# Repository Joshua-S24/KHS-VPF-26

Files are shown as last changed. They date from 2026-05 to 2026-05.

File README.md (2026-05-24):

# Tiger Tower I

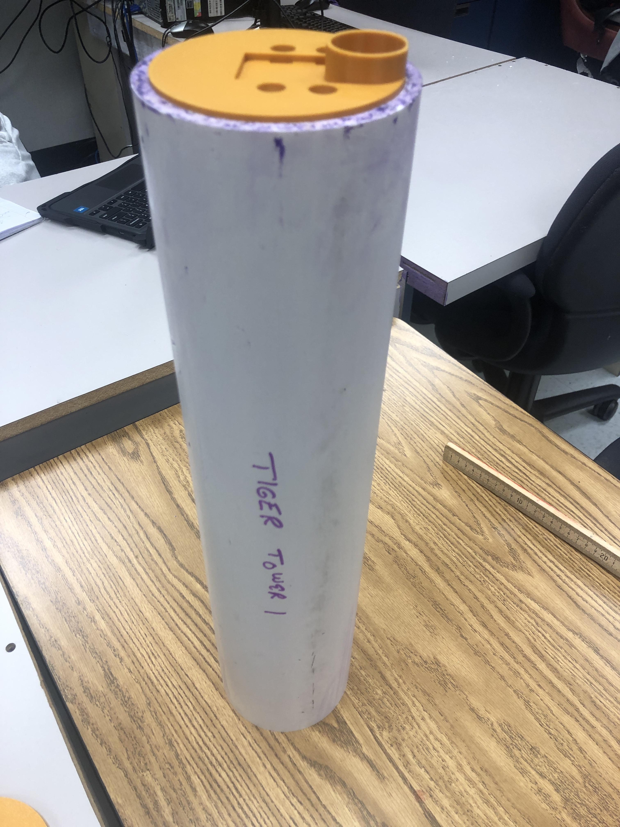
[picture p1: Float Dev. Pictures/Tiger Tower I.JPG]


This is a public repository for the Kerr Engineering Club’s vertical profiling float: Tiger Tower I. Tiger Tower I was built for the purpose of completing the 4th (ranger-class) task in the Houston Marine Advanced Technology Education (MATE) Remotely Operated Vehicle Competition.

Task Preview: https://20693798.fs1.hubspotusercontent-na1.net/hubfs/20693798/2026/2026%20MATE%20Floats%20Preview%20Mission\_RANGER\_PIONEER\_FINAL\_Updated\_10\_1.pdf

This repository is primarily meant for current members of the **Kerr Engineering Club** who are interested in the MATE ROV competition and are also interested in working on a vertical profiling float. Tiger Tower I is **incomplete** as of the 2026 competition, so this is meant to be documentation for the float to complete and improve upon it. However, non-members who are participating in the competition can feel free to use this repository as a source of information about building a vertical profiling float.

There is also a logbook that details the process of developing Tiger Tower I, which goes into further detail about the tools and decisions made during its design and construction.

Below is the documentation for the main components of the float. This was written after the competition to provide a more comprehensive and streamlined explanation of Tiger Tower I.

### Tools Used

Onshape: https://www.onshape.com/en/ (Modeling)

STLGears.com: https://www.stlgears.com (Gear Model Generation)

Gear Generator 2: https://geargenerator.com/beta/ (Gear Simulation)

## Goal

The goal was to create a vertical profiling float that can, without manual input, submerge to a given depth of a large body of water, remain stationary for 30 seconds, record the water pressure and depth between 5-second intervals, re-emerge, and wirelessly transmit data to a computer.

## The Chassis

### Body

The internals of the float are contained in a 4-inch nominal schedule 40 PVC pipe. The length of this PVC pipe was originally 56 cm before being shortened to 50 cm. (Based on measurement, the inner diameter was approximately 3.956 inches, and the outer diameter was approximately 4.504 inches.)

The reason I chose a PVC pipe was simple: it was readily available, sturdy, and buoyant. The buoyancy of a sealed PVC pipe suits our water-based buoyancy engine. The shape of the PVC pipe was cylindrical, which means that the buoyant force acting upon the float would be uniform, and not biased on one side or another. One key drawback, however, is that PVC pipes are opaque, meaning electronics inspection will require the unsealing of the float. Additionally, the 2026 competition required a safety handle that the ROV could use to retrieve it. While a design was not made in time, it was likely that a thin, 3D-printed ring with 4 support beams attached to the chassis would’ve been used to maintain the uniform shape while minimizing the additional surface area.

That particular size of the PVC pipe was chosen since it allowed for much leeway in the development of the float’s components. The long-term plan was to develop the parts, then cut the chassis down to the minimum size possible. However, the sheer size of the pipe meant that even with the largest syringes available, the float would never have been able to sink.

### Compartment Layout

The float was separated into two main compartments: the electronics and the buoyancy engine. The electronics were kept at the top. This is mainly because vertical profiling floats require radio waves to communicate wirelessly. However, the range of radio waves can be adversely affected underwater. While the float is on the surface, some amount of the bottom of the float must be submerged, meaning that the electronics should be on the top part of the float for the sake of communication. This meant that the buoyancy engine was at the bottom. Additionally, a ballast was planned to also be near the bottom of the float to provide stability.

## Buoyancy Engine

### Chosen Type of Buoyancy Engine

While a buoyancy engine was not required for the completion of this task, it was encouraged by the competition. There are two main types of buoyancy engines we could have used: an air-based buoyancy engine and a water-based buoyancy engine.

An air-based buoyancy engine would require an internal air tank, a bladder to contain the air, and a pump. The float must also experience negative buoyancy by default. The bladder must also be exposed outside the float. While the bladder is deflated, the float sinks. To go back up, air could be pumped into the bladder to give the float more volume, giving the float positive buoyancy.

A water-based buoyancy engine would require a syringe and a motor-powered linear actuator. A syringe can be used in place of a pump and bladder because it can store, intake, and expel water with the help of a linear actuator. The float would begin at positive buoyancy before the syringe draws in water, causing it to sink. Once the float needs to surface, the syringe can expel the water to bring it back to positive buoyancy. For its simplicity, we picked the water-based buoyancy engine.

### Syringe

I had the option of using a large syringe or multiple small syringes. While a large syringe could’ve easily been used, I had to consider the size of the syringe relative to both the electronics compartment and the mechanism needed to push and pull the syringe. Additionally, the more water is taken in, the more power the motor would need. Finally, the float would only need just enough water for it to sink and float. Sinking and rising slowly would’ve been beneficial in finding neutral buoyancy, which was necessary in keeping the float still. Therefore, I decided to use three 60 mL syringes, which stored a total of 180 mL. In hindsight, this was far from being enough to sink the float due to the size of the chassis.

### Linear Actuator

The linear actuator, in retrospect, easily took the most time out of this project. Despite it still being a non-functional state, I believe that it was a necessary sacrifice in the long term due to the potential for mass-producing a linear actuator. The reason why I decided to make a linear actuator instead of buying one was simple: cost. While the cost of linear actuators isn’t insurmountable, our club does not currently have the funds to casually buy an actuator. The cost of one relative to every other component of the float would mean that I would have to design the entire float around it. While that is not necessarily a downside, making adjustments to the float’s design could become restrictive by buying an actuator. Moreover, the power that a linear actuator offers is simply too much for what is required for the buoyancy engine. The lower I managed to find was able to exert a force of 40 pounds, which could actually end up compromising the float if I did not implement limit switches for whatever reason. I would need no more than 5 pounds to extract the maximum amount of water out of the largest syringe I could find. Therefore, I found it better long-term to design and 3D-print parts of a weaker linear actuator that can be mass-produced and adjusted to my liking.

The actuator itself had a 4:1 gear ratio, which was presumably sufficient for expelling and drawing in 180 mL of water. The gearbox and gears were 3D-printed with PLA, while the arm and its container were made out of PVC pipes. The PVC arm contained a cork with an indent and a hole made to fit an 1/4 in. nut and bolt. This would let the motor rotate the bolt, which would extend the arm up to a given stroke length while exerting force. Since the barrel of our syringes was 5 inches, the stroke length had to be 5 inches as well, which meant that I needed to reserve more than 10 inches (25 cm) of space for the buoyancy engine. For future attempts at making (or buying) a linear actuator, I would prioritize reserving space above all else, because my design was too long and wide.

## Electronics

### Circuitry

The electronics compartment had 2 sections. The first section, located at the top of the float, would have had the batteries, the switch, the fuse, the microcontroller, the motor controller, and the pressure sensor. The float itself was powered by 4 AA NiMH batteries, which possessed 4.8V in total. There was wiring that led to the second section, which contained the motor for the buoyancy engine and limit switches for the linear actuator.

The linear actuators required limit switches to prevent over-extension or over-retraction without tripping the fuse. This helps control the stroke range of the actuator. Most linear actuators possess power diodes so that if the arm triggers a switch, the arm cannot go past the switch and can only go in the reverse direction. However, we had no diodes that could handle more than 1 amp, meaning that I had to hook up the limit switches to the digital pins of a microcontroller. I then programmed them so that if there was a signal on the digital pin, then the function to extend in a given direction would be disabled.

At one point, there were also plans to include an SD card module. This ended up being discarded due to a lack of time and necessity, as the Pico had enough storage to store data for at least two vertical profiles.

### Microcontroller

The microcontroller I chose was the Raspberry Pi Pico W. This was because the microcontroller was compact, had innate Wi-Fi and Bluetooth capabilities, and possessed the computing power needed for the task. The Raspberry Pi Pico W also has an on-board buck boost converter, which can convert a range of voltage inputs to 5V, which can then be used to power a variety of electronics on the float.

### Data Recording and Transmission

The pressure sensor is the main way for data to be recorded. The sensor needed to be hooked up to a power source and an analog pin to return readable data. This sensor would then emit a signal between 0V and 3.3V, which would be used to determine the pressure of the water, as well as the current depth of the float, based on the density of the water. This depth could then be used in an algorithm to find neutral buoyancy, adjusting the syringe if it changed in a given time interval.

To communicate with the mission station, I wanted to use a Wi-Fi signal with a website interface. While this wasn’t ineffective, the nature of Wi-Fi’s high frequency meant that it could not penetrate through water easily. This meant that the float could only maintain a connection with the mission station while it was on the surface, and submerging to complete a vertical profile would break that connection. While workarounds were possible, an alternative could have been to use a microcontroller with a LoRa radio, like the Adafruit LoRa Radio FeatherWing. Long Range (LoRa) signals are designed to transmit small chunks of data across long distances, which would have been perfect for this scenario. Additionally, having a LoRa signal receiver on the mission station meant that we could avoid the hassle of having to connect and reconnect for every attempted profile.

## Conclusion and Future Improvements

The main obstacles in the completion of this project were time and a lack of manpower. While I had a design team for the float, due to other obligations, they were not able to assist. Taking rigorous courses like AP Calculus BC, AP Physics C: Mechanics, and AP Physics C: Electricity and Magnetism forced me to manage my time to contribute. Additionally, other team members were working on the ROV, which made up 75% of the competition. Therefore, I took it upon myself to focus on the float so that, at least, the float would be working well before the next competition.

With that being said, there are some glaring issues with this design that need to be addressed by future team members. One focal point of any vertical profiling float design is volume. Tiger Tower I was simply too big and did not respect the density of PVC, meaning that even with a large, 500 mL syringe, it would still need around 2.5 lbs of ballast to even reach neutral buoyancy. To put it succinctly, it either needs to be smaller or the chassis material needs to be replaced with something denser.

However, making the float smaller is easier said than done. While the electronics compartment won’t struggle with a decrease in size, the current linear actuator design would beg to differ. If we still wanted to commit to a custom-made linear actuator design, it would be best if, somehow, the length of the engine could decrease relative to the decrease in the chassis’ length. Additionally, the actuator’s design is too wide and should be streamlined to fit into a smaller diameter.

Finally, the Raspberry Pi Pico W can meet our requirements, but for the sake of convenience, it may be better to just buy two Adafruit LoRa Radio FeatherWings to make communication easier. This way, we can eliminate the need for an online interface and the need to re-establish a connection, only relying on choosing a certain frequency to receive.

Even though this project failed, I was able to gain a whole new insight into the process of designing a vertical profiling float and robotics in general, thanks to this competition. Our circumstances were dire, and yet our team managed to place 3rd in the Houston MATE ROV Competition, despite it being our first time competing, so I believe that our next team will have much more to offer. Additionally, doing research for this project took up a good chunk of time, and even now, many oversights could’ve been addressed sooner. I hope my findings are useful to future club members interested in building a vertical profiling float, as well as other students interested in this sort of technology.

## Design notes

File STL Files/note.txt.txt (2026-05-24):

Below are some details that may or may not have been mentioned.

The arm itself was a 1/2 in. Schedule 40 PVC Pipe. The pipe combined with the Nut Holder had a length of around 5 inches, which was the intended stroke length. I don't necessarily recommend that this particular measurement is used; rather, these were the measurements that the STL files were built around.
The nut and rod used were probably not M7. It was far more likely that both were 1/4 inches.

Gear Generator Schematic: https://geargenerator.com/beta/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
Gear STL File Source: https://www.stlgears.com/
The gearbox had a 4:1 gear ratio, and all gears had a module of 1 and a pressure angle of 25 degrees. When making your own gearbox, it is best to distance each gear based on the inner diameter (excluding teeth) to ensure proper meshing. There were three gears in total. The smallest gear had ten teeth and was placed on the motor directly. The compound gear had a 20-tooth gear on the bottom and a 12-tooth gear on the top. The compound gear was placed on a rod with a single R4AZ bearing. The final gear was a 24-tooth gear that was placed on the threaded 1/4 rod.
Additionally, most of the holes these gears had were INACCURATE, and had to be adjusted in some way after they were printed.

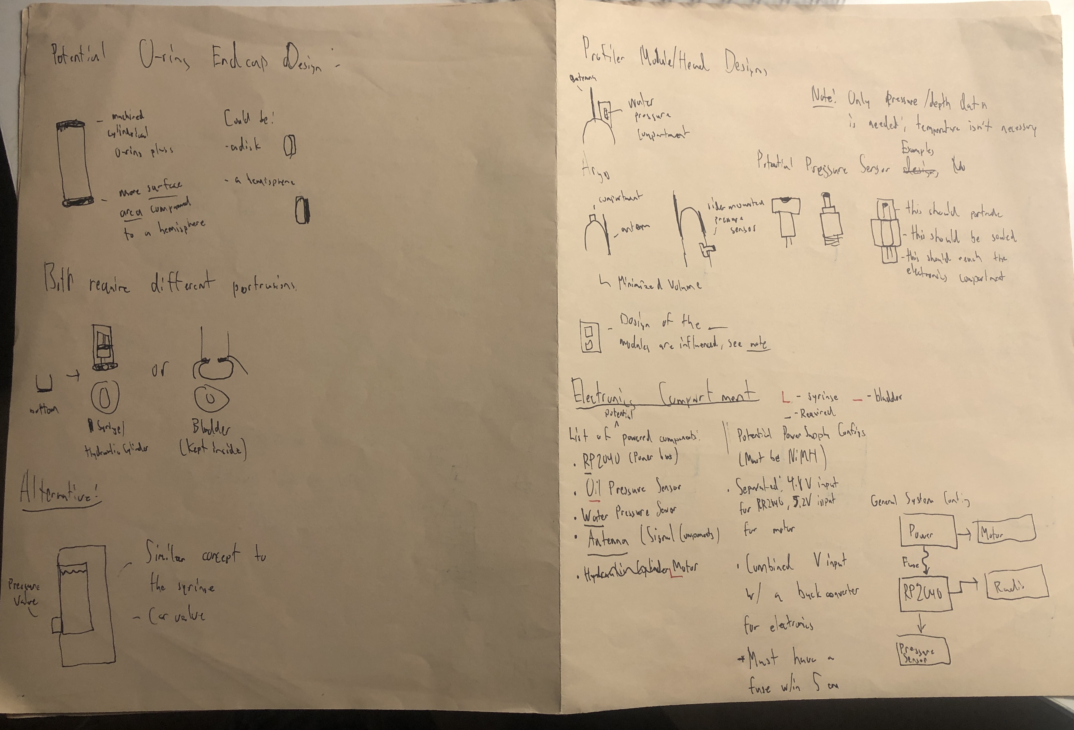
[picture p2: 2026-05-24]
Float Dev. Pictures/Rough Concept Draft Page 2.JPG

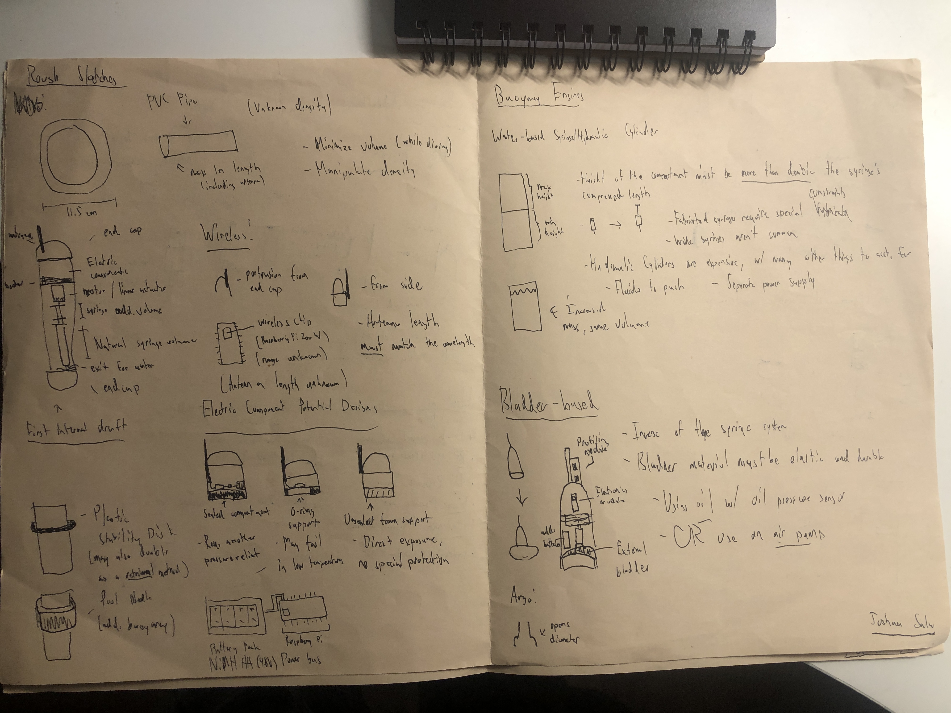
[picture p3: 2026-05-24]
Float Dev. Pictures/Rough Concept Draft Page 1.JPG

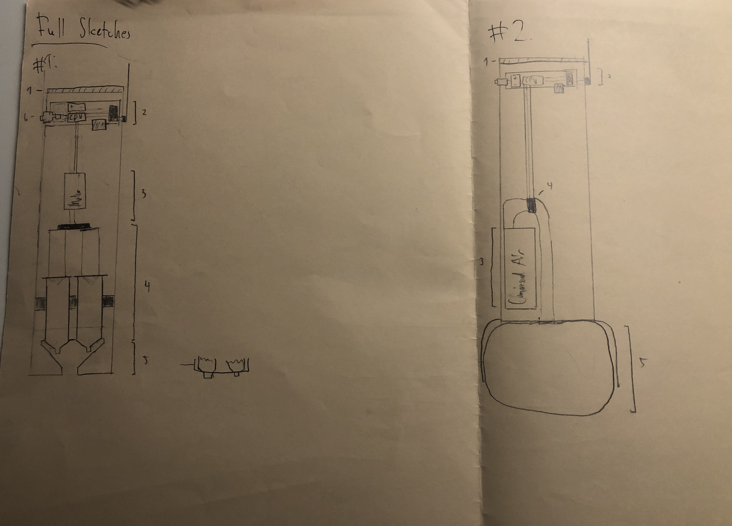
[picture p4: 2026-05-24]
Float Dev. Pictures/Buoyancy Engine Sketches.JPG

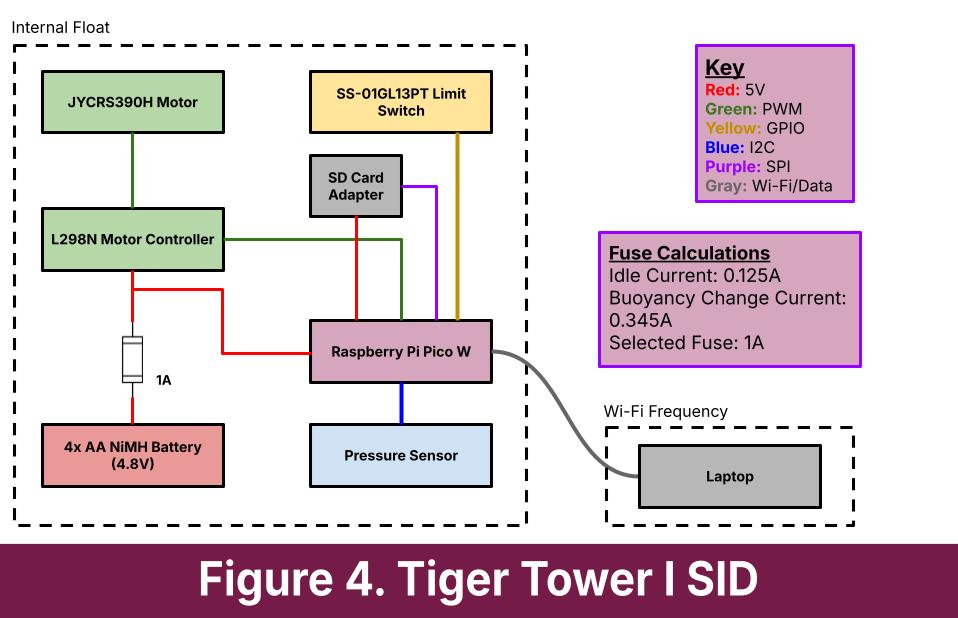
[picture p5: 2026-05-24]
Float Dev. Pictures/VPF SID Draft.jpg

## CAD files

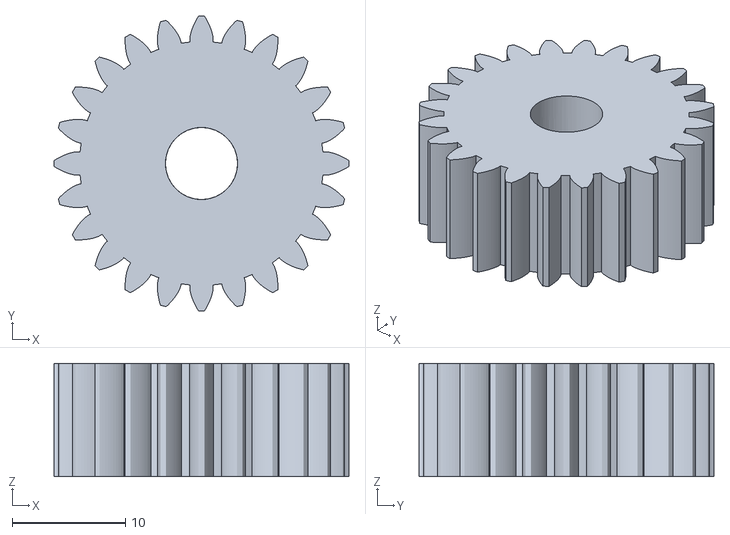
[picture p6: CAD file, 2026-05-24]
STL Files/Gears/NSpur_M1_Pa25_Z24.stl
26.0 x 26.0 x 10.0

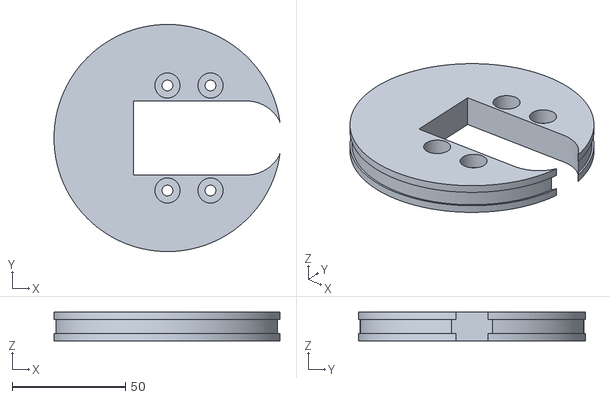
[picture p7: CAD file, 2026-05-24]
STL Files/LAGearbox/LAGearbox - HolderV2.stl
100.0 x 100.5 x 12.7

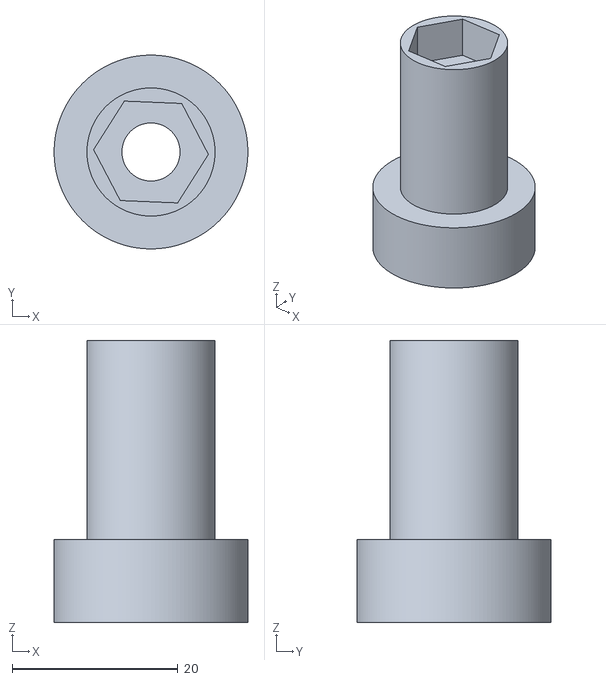
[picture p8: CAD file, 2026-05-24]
STL Files/M7NutHolder - V2.stl
23.4 x 23.4 x 34.0

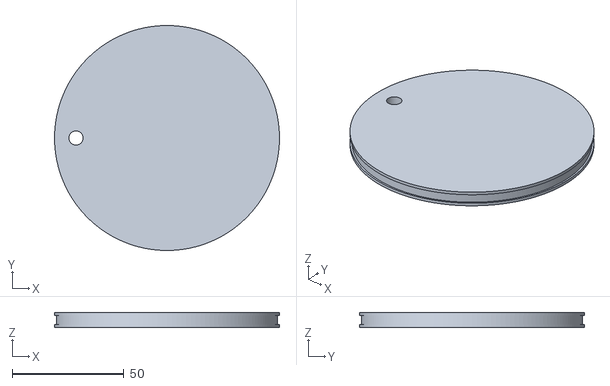
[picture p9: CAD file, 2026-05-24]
STL Files/Electronics Plate - V2.stl
100.5 x 100.5 x 6.50

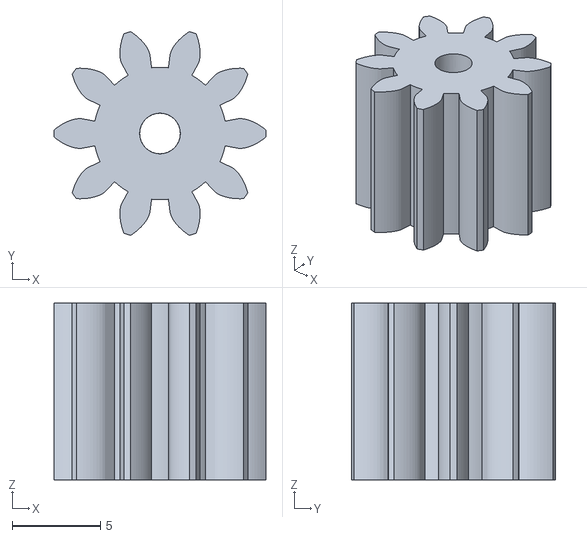
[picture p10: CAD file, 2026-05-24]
STL Files/Gears/Gear1-Spur_M1_Pa25_Z10.stl
12.0 x 11.5 x 10.0

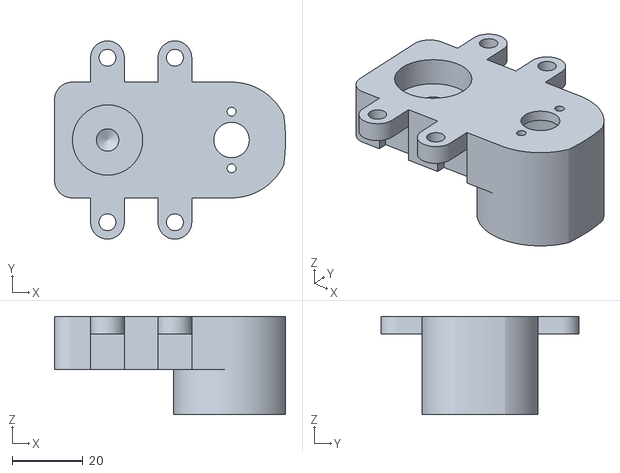
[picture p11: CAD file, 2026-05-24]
STL Files/LAGearbox/LAGearbox - Part 1.stl
65.2 x 56.0 x 27.7

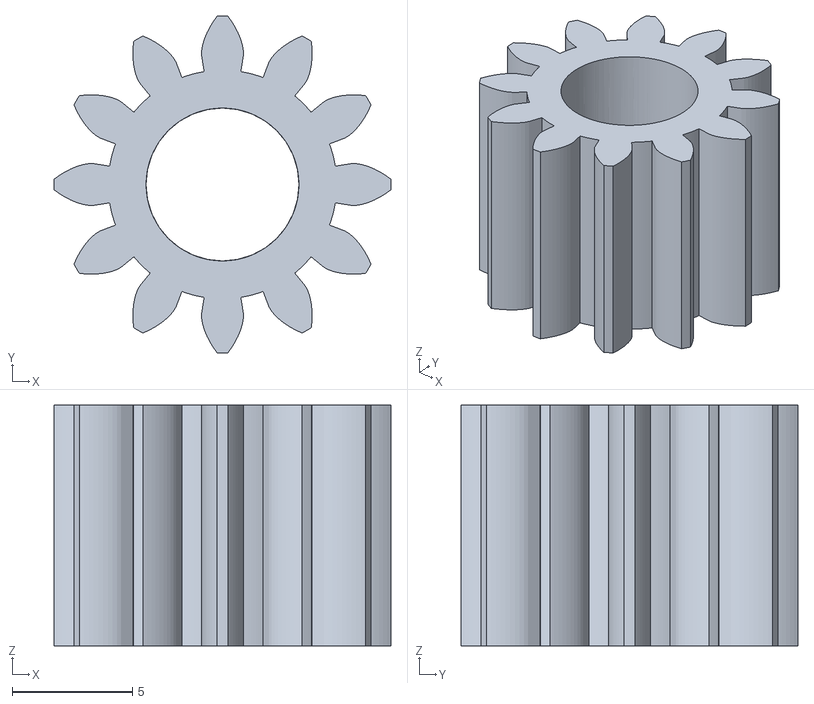
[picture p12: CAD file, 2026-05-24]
STL Files/Gears/NSpur_M1_Pa25_Z12.stl
14.0 x 14.0 x 10.0

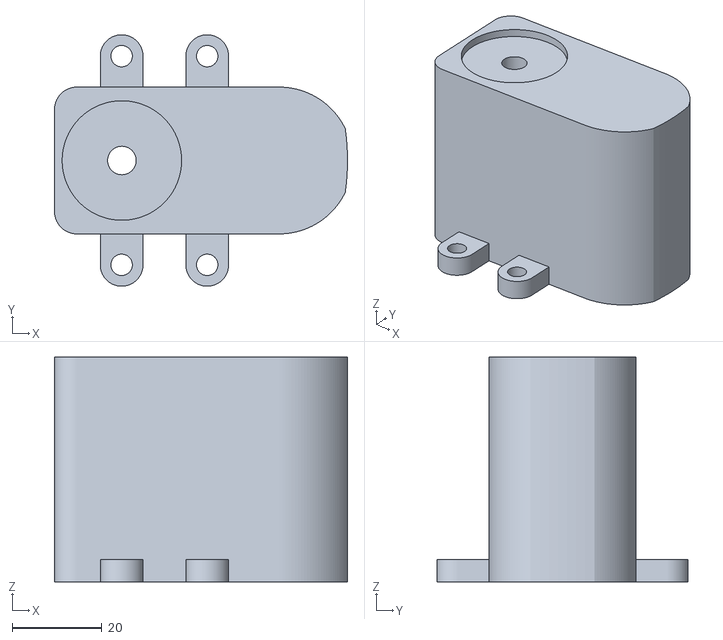
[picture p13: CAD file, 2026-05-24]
STL Files/LAGearbox/LAGearbox - Part 2.stl
65.2 x 56.0 x 50.0

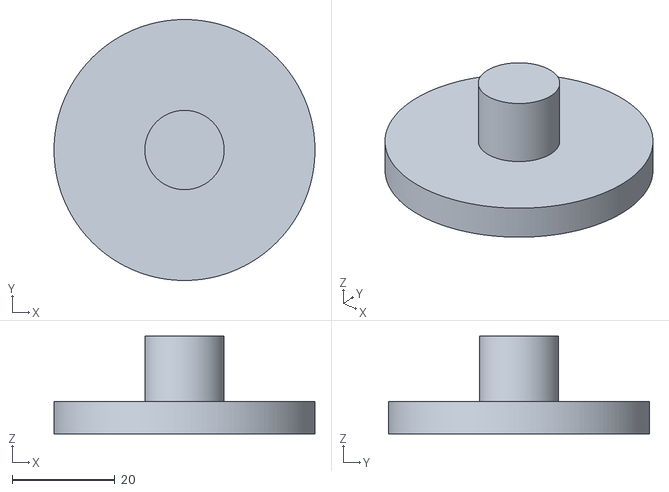
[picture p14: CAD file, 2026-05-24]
STL Files/Piston.stl
50.8 x 50.8 x 19.0

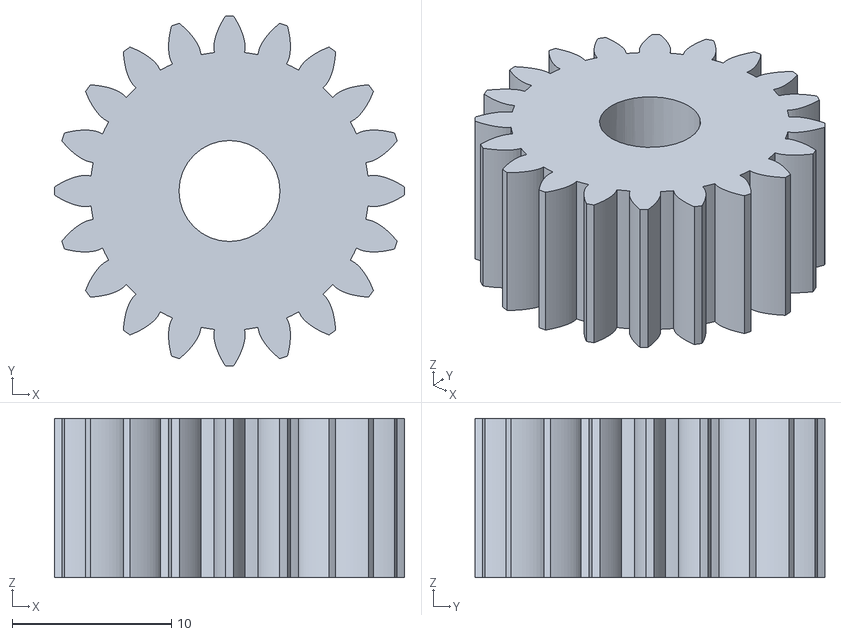
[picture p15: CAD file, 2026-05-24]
STL Files/Gears/GearboxSet2 - 20TSpurGear.stl
22.0 x 22.0 x 10.0

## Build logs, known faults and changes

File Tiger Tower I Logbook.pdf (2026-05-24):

# Tiger Tower I Logbook

## Written By Joshua Salu

## Foreword

This is a public copy of the logbook I made for the vertical profiling float that is to participate in the Houston MATE 2026 competition under the Kerr Engineering Club, also known as Kerr Robo Incorporated. This logbook will often reference links and files that may not be accessible; however, the intent of this logbook is to give insight into the construction of the float without external resources.
Additionally, while there was initially supposed to be a design team, due to student-related circumstances as well as a lack of time, all of the work related to the vertical profiling float was delegated to me, while all other team members were to work on the ROV. While I was unable to finish the float due to the urgency of the ROV, I have made this logbook public so that future members of the team can learn from my efforts.

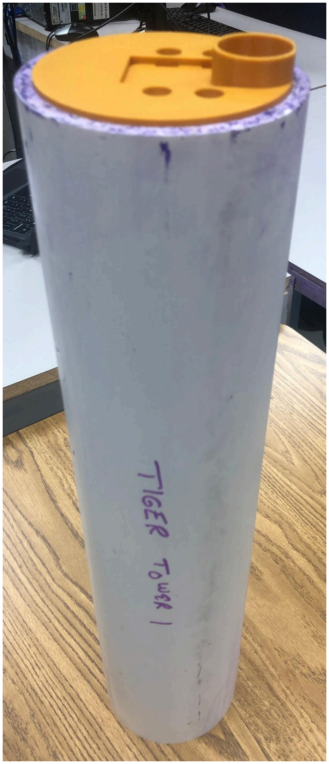
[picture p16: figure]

1/15

## Beginning Task #4

Today, the meeting was dedicated to coming up with a design for the vertical profiling float in task #4 of the MATE ROV competition.

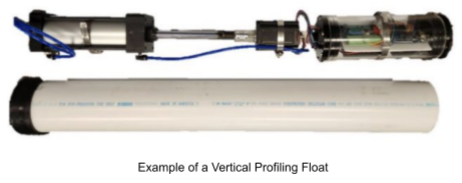
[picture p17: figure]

Task #4 involves constructing a vertical profiling float separate from the ROV to submerge in water and complete vertical profiles autonomously. The reason why I decided to prioritize this first is that this component is separate from all other tasks. To elaborate, tasks 1-3 are only possible with the ROV. Additionally, the ROV itself is being developed by Abdul right now, meaning very few tasks can be progressed. Therefore, it would be best to develop the float simultaneously.

One of the first things decided was that I would use a PVC pipe as the chassis. PVC is sturdy, reliable, cheap, and readily available. There are multiple ways to accomplish the construction of a vertical profiling float, and one of the key decisions in this process is the choice of our buoyancy engine. However, this choice, and the rest of this process, is complex and will require additional research to make some drafts.

2/10

After conducting extensive research, I have split up the vertical profiling float into 3 parts: the chassis, the electronics compartment, and the buoyancy engine.

## Chassis

The chassis is mostly simple in concept: it protects all internal components of the float. However, where it gets complex is the required holes, sealing, and pressure relief.

The chassis requires at least one hole for the pressure sensor, which will be required to record data during each vertical profile. An additional hole will also need to be made for a switch, so that it can be deployed by hand. The diameter and location of this hole are currently unknown, although it will likely be within the electronics compartment. The exact means of sealing the chassis is currently unknown. Any necessary holes will be sealed with silicon or epoxy. However, the float itself requires some form of pressure relief. There are two ways to accomplish this: corks or o-rings. Corks (or rubber stoppers) can be friction-fit into a hole to prevent fluids from coming in while allowing for pressure relief. O-rings are rubber gaskets that fulfill a similar function, but only when fit to the material. (In other words, the o-ring must be wrapped around something so it can seal the compartment.) Corks are easier to remove and modify, but take up additional space. O-rings take up less space but cannot have their circumference manipulated by any means. As of now, the current diameter of the chassis is 10 cm, and its height is around 56 cm.

## Electronics Compartment

The electronics compartment is meant to power the float so that it can record vertical profiles automatically. The key components of this compartment are the power source, the fuse, the motor, the pressure sensor, the breadboard, and the microcontroller. Currently, I am planning to use 4 AA NiMH batteries to power the float. This will provide us with a voltage of around 4.8V. NiMH (Nickel Metal Hydride) batteries are one of two allowed types of batteries for providing power. NiMH batteries can also be recharged. As per MATE’s safety regulations (ELEC-NRD-003), I must use a 2 amp fuse (if I am using NiMH batteries), and it must be within 5 cm of the power source. These batteries will also power a 5V-12V motor, but the details of the motor itself are currently unknown. The pressure sensor will also require power of its own, and its details are also unknown. The breadboard itself will likely be a typical half-size perma-proto breadboard. The microcontroller itself will be a Raspberry Pi Pico W. This microcontroller was chosen due to its compact size, low price, and innate wireless capabilities. Should the wireless capabilities be insufficient, a radio module can be connected.

## Buoyancy Engine

The buoyancy engine is the most important part of the float, as it decides the design of the majority of the float, as well as how it will manipulate the float to conduct vertical profiles. For context, all objects on Earth are subject to gravity, which is mass times the acceleration from gravity (9.81 m/s^2). All objects submerged in water experience a force of buoyancy opposite to gravity, which is the product of fluid density, gravity, and the volume of the object. For an object to float, the buoyant force must exceed the gravitational force. The opposite is true for an object to sink. An object will remain in equilibrium if the gravitational force and buoyancy are the same. In other words, if those conditions are met, the object will neither sink nor float and remain still, which is vital to taking vertical profiles at any given depth.
There are two main types of buoyancy engines: water-based engines and air-based engines. Both manipulate the force of buoyancy within water to float, sink, or remain neutral. Water-based engines use either a large syringe or a hydraulic cylinder to intake water, increasing the mass of the float to strengthen the force of gravity. Air-based engines use a bladder and an air tank (or some other fluid) to expand the bladder, increasing the volume of the float to strengthen the force of buoyancy. It should also be noted that water is many times denser than air. To be specific, water has a density of 1,000 kg/m³, while air has a density of about 1.225 kg/m³ at sea level. (Density can vary based on conditions, like temperature). Given our limitations, it is likely best to design a water-based buoyancy engine using syringes.

2/13

We have made the decision to use a water-based buoyancy engine for the vertical profiling float. Because I am using syringes, it is guaranteed that I will use a motor to construct a mechanism that converts rotational motion into translational motion. To elaborate: as the motor revolves, an object connected to that actuator will move forward and backward.

## Syringe Choices

There are two potential designs to consider: one using smaller syringes and one using a custom, larger syringe.

The former involves using readily available syringes to intake water. They will take up less space and require less force to push down. In exchange, the syringes cannot intake as much volume of water, which could be insufficient for functionality in the worst-case scenario. In the average case scenario, this could lead to a slow descent, which is not inherently negative but should be accounted for.

Currently, a syringe holder has been designed to fit 3 60 mL syringes, while also functioning as a cork to do away with the need for adhesives. (This could change in the future.)

A larger custom syringe will be harder to implement, as it will require a friction-fit disk, as well as more power from the motor that could exceed our given limit. It will also be larger, requiring more space in the chassis. In exchange, a larger syringe can ensure that the float can sink or float, though finding neutral buoyancy may be harder as a result. Currently, I will go with the first design unless it is found that the changes in mass provided by the smaller syringes are insufficient.

## Linear Motion Mechanisms

The mechanism itself can also have two (or more) designs. One option is to use a linear actuator using a screw mechanism. However, the implementation of this design is complex and must be researched. Additionally, a linear actuator must be designed rather than bought. A bought linear actuator will increase the cost by a great amount, while also potentially being unfit for our float. Creating a linear actuator will give us more agency in the design while also keeping costs low.

Therefore, it may be simpler to go with a slider-crank linkage (or other similar mechanisms like the sun-planet gear or scotch yoke). All three mechanisms use an apparatus with a motor attached to the center and a rod being held to prevent vertical movement, resulting in the rod oscillating horizontally. (Implementation of the linear actuator is not limited to these options; these are merely suggestions at the time of writing. All given flaws of these mechanisms are not fully realized as of yet.)
In both cases, the linear actuator will be attached to a piston that will connect to the syringe(s).
2/18

For now, I’ve shifted my focus to the construction of the electronics compartment. As mentioned earlier, the key components of this compartment are the power source, fuse, motor, pressure sensor, breadboard, and microcontroller. The switch will also be considered a component of the electronics compartment. This switch can be implemented in two ways.

## Switch Designs

Lever Switch w/ Cap

Pros | Cons
- PVC structures already exist that can make implementation easy ● Easy to tell if the float is on or off | ● Cannot be toggled at a moment’s notice ● Is not sealed at all points in time; improper sealing can cause extreme damage w/o safeguards ● Would likely require a protrusion; depressing the material could worsen the previous con

Push-Button Switch w/ Membrane

Pros | Cons
- Faster toggling ● Always sealed | ● Harder implementation time; the design would have to consider many factors on the outside, compared to a lever switch ● May require a visual indicator to tell if the float is powered or not

For now, I will go with the lever switch. Ideally, the lever will be small, such that it can be toggled with one finger. This way, I could end up using a membrane instead of a cap (if possible).

To allocate space for this compartment, the breadboard and microcontroller will be given a container (dubbed the electronics hub) so that all wiring is connected and made easily accessible. Additionally, the power source will be kept separate from this hub to accommodate the removal of batteries. The fuse, consequently, will also have to be kept outside of the hub to comply with regulations. To elaborate, the fuse must be within 5 cm of the power source. This also means that the switch will need to be kept in close proximity to the power source. The motor and pressure sensor will also be kept separate from the hub, but their wiring will connect to the hub to be controlled by the microcontroller. Finally, it was found that powering the motor and pressure sensor using the 3.3V out pin of the Raspberry Pi Pico W is inadvisable. Therefore, I will supply power to these devices separately, which means that I will be using 9-12V instead of the planned 4.8V. This may also involve the use of a step-down transformer within the circuit. With this in mind, I have begun to design potential designs and prototypes for the electronics hub.

2/23

Custom designs for the electronics hub have been drafted. The hub itself can be made of currently existing objects, like jars or PVC pipes. They are easy to seal and drill holes in, but their size and design cannot be customized easily. While this option isn’t ruled out (by virtue of convenience), I decided to create designs on a platform called Onshape. Onshape is a free CAD system that uses cloud architecture. We’ve decided to use this program because it can be accessed on any computer, and members can collaborate on the same design.
To make a competent design, I would decide on using 3D printed prototypes for precise measurements and features. Additionally, 3D prints are not perfect, and may have defects that may or may not be able to be fixed. Any imperfections or oddities may also affect how I approach the remaining tasks. Finally, these designs will also help us evaluate the use of PLA and other 3D printing filaments to make the shell, as well as other
components. Therefore, I have come up with designs to observe and test various characteristics that can be utilized in the final design. Using Onshape, we’ve been able to fully design 2 prototypes for the hub.

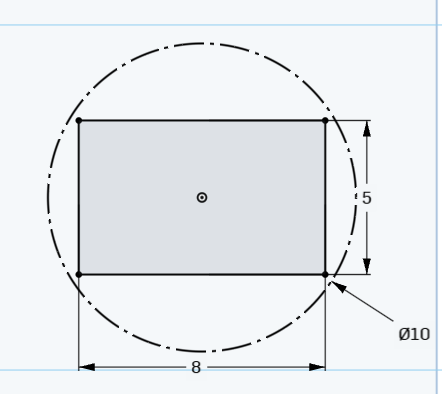
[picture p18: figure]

As a precedent, no hub design should exceed 8 cm in width or 5 cm in length. This is to respect the 10 cm diameter.

## 1st E. Hub Prototype

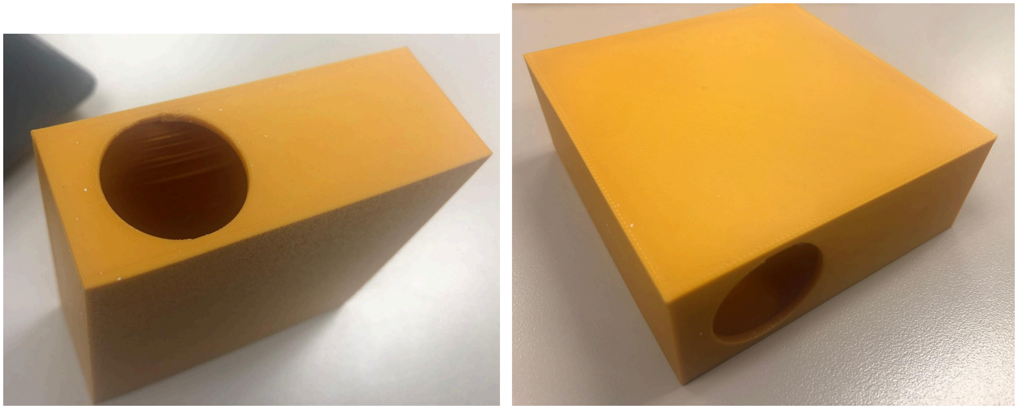
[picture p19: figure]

(Note: For testing, a shell with one hole will be used.)
This prototype uses thin walls and largely relies on a cork to provide pressure relief. However, upon printing, I noticed that side-printed circles are prone to imperfections. Additionally, the pressure relief hole itself is comparably shallow, only 0.25 cm in depth. This could affect a cork’s ability to seal the compartment. The pressure relief hole itself has a slight defect, as well. This could be due to being printed on the side, instead of at the top or bottom.
Additionally, this design cannot currently be opened, though this limitation could be mitigated by accommodating adjustments only to the microcontroller, sensor, and battery.

## 2nd E. Hub Prototype

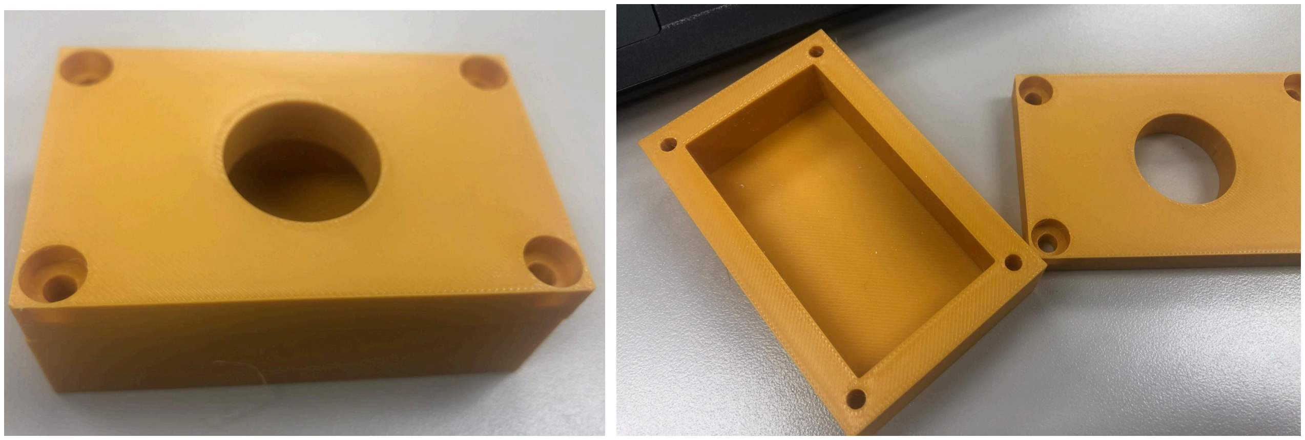
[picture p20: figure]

This prototype uses a thicker design that is separated into two parts to be combined with screws. This design allows for revision of components, although using screws is not the only way. Additionally, the thicker design does leave less space for electronics, though this can be mitigated by separating the battery and pressure sensor from the shell. Doing this, however, has its own complex requirements to ensure modularity.
Finally, the actual fabrication showed that the bases were not made flat, which could heavily reduce the effectiveness of these screws.

2/27

Today, two tests have been carried out on both prototypes: a durability test and a sealing test.

## Durability Test

### Rationale

The durability test was conducted to ensure the compartment can withstand minor forces within the float. This is to make sure that this compartment isn’t destroyed before pressure is relieved, and that it can retain its function should the float be damaged (or rocked) from the outside. The durability of the compartment shell will mostly rely on thickness, so failing this test would require a revision of the shell’s thickness. In other words, this test is meant to optimize the thickness of the shell’s walls. If a pre-existing container is used instead, then this test can be used to evaluate an acceptable degree of durability for said container.

### Procedure

The shell will be subjected to 5 lbs of force for 15 seconds over the course of three trials. If there is no sign of damage (bending, cracking), then the shell passes the test.

### Data

| Trial 1 (5s) | Trial 2 (10s) | Trial 3 (15s)
Prototype 1 | Pass | Pass | Pass
Prototype 2 | Pass | Pass | Pass

## Sealing Test

### Rationale

Instead of another O-ring (that may need to be custom-fit within the file itself), a cork can be used to seal the shell. The cork will be sufficient for pressure relief, but it may also need protection from water, should it enter the float. If the seal fails, then any water will compromise the entire float. This test can also help evaluate if the location or type of hole needs to be changed, or if another method should be used entirely. Should both designs fail this test, then a pre-existing container will likely be used since most already provide competent sealing.

### Procedure

The shell will be sealed with a cork. The shell will be exposed to light, running water from above for 5 seconds, with the cork side facing up. Then, the shell will be unsealed. If the shell has no water inside, then the shell passes the test. In each trial, the cork should be adjusted to ensure maximum sealing.

### Data

| Trial 1 | Trial 2 | Trial 3
Prototype 1 | Fail | Fail | Fail
Prototype 2 | Fail | Fail | Fail

## Conclusion

The results of the durability test showed that Prototype 1’s thickness was sufficient in withstanding minor forces beyond 15 seconds. Prototype 2, naturally, was also sufficient, but the results of Prototype 1 prove that thick walls are not necessary to provide resistance against forces.
The results of the sealing test showed that the usage of corks may not be as viable for protection from water. Despite this, corks can still be used, although this may require more precise fitting (and even attachments). Alternatively, water protection can be sacrificed entirely, and the cork can be oriented near the bottom to use gravity. Ideally, a solution can be found that provides water protection and accounts for any known defects of the prototypes, while also being non-permanent to allow for modifications to the electronics.
In any case, pre-existing containers will be used from now on. However, these findings are useful for the evaluation of the hub’s requirements and the potential benefits and flaws of our 3D prints.
3/12

## Float Updates

Concerning the vertical profiling float’s buoyancy engine, it has been decided that a slider-crank mechanism will be used as a linear motion mechanism. Out of the named mechanisms (save for the linear actuator), the slider-crank mechanism can handle the most load. However, the motor will likely need to be oriented sideways, meaning that additional mechanisms must be put in place to align the rod in the middle for the piston. This could make fabrication more difficult than expected. However, this does give us the opportunity to create gears to apply a stronger linear force, which is something that would’ve needed to be done for both designs anyway.
Additionally, a week ago, an initial circuit design was created.

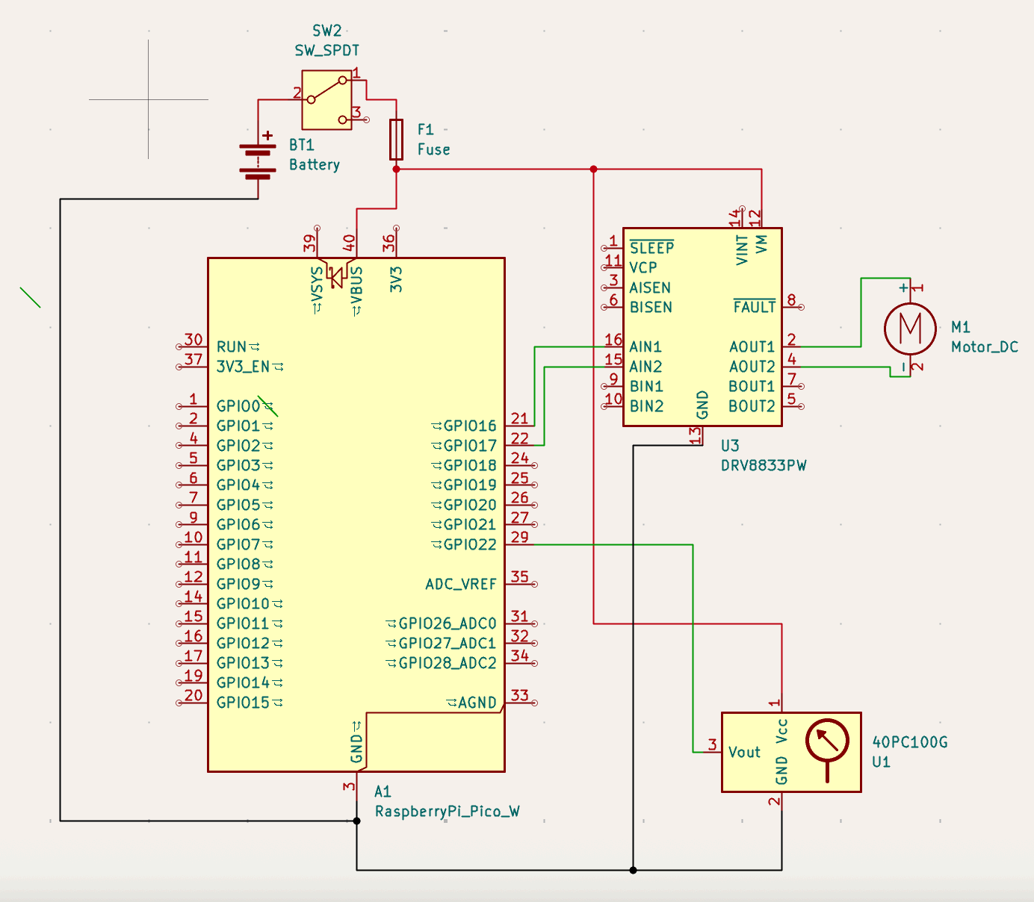
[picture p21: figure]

Certain components were accounted for, such as the separation of the motor and pressure sensor, the addition of a motor controller (DRV833), and the use of a Raspberry Pi Pico W. Further research revealed that the Raspberry Pi Pico W is not suitable for underwater communications. While it is a known limitation that frequencies can be absorbed by water, this can be mitigated by restricting communication to only occur when the float is not fully submerged. Additionally, placing radios in a plastic compartment is safe, since signals can pass through. A longer-range alternative would be the Adafruit Feather RP2040 with an RFM95 LoRa Radio. This uses the same RP2040 chip that a Raspberry Pi Pico W uses, while boasting an alternative radio for long-range communication. However, this is more expensive than the Pico (by about 4 times). Additionally, I can connect a separate radio module and antenna. The choices of using a different microcontroller, using a separate module, or keeping the Raspberry Pi Pico W are yet to be explored as of writing.

3/17

## Additional Float Update

The decision to use a slider-crank mechanism has been rescinded. Research showed that while it can be used in syringes, it lacks the precision required to manage the buoyancy of the float, which is extremely vital to this task. Additionally, two linear actuator designs have been found that are less complex to design than previously anticipated. In any case, a linear actuator will be used for the buoyancy engine to ensure precision when controlling buoyancy.

The construction of the linear actuator will require the use of a motor, bearings, a threaded bolt, and a driver nut. The actuator transforms rotational motion into linear displacement by having the motor rotate the bolt. The bolt itself will not experience linear displacement due to being held down; instead, an arm will extend via the driver nut. The extension of this arm is slow, but in exchange, the torque provided by the motor will be converted into a high amount of force. The arm will have a piston so that this force can be used to push and pull the syringe. It is important that the force is sufficient to push down a syringe filled with water, especially if it has a relatively large volume. This is because water is many times denser than air, requiring more work to push the water from the syringe.

## Buoyancy Engine Motor

The motor I will be using for the float is the AUTOTOOLHOME 6V-12V DC motor.

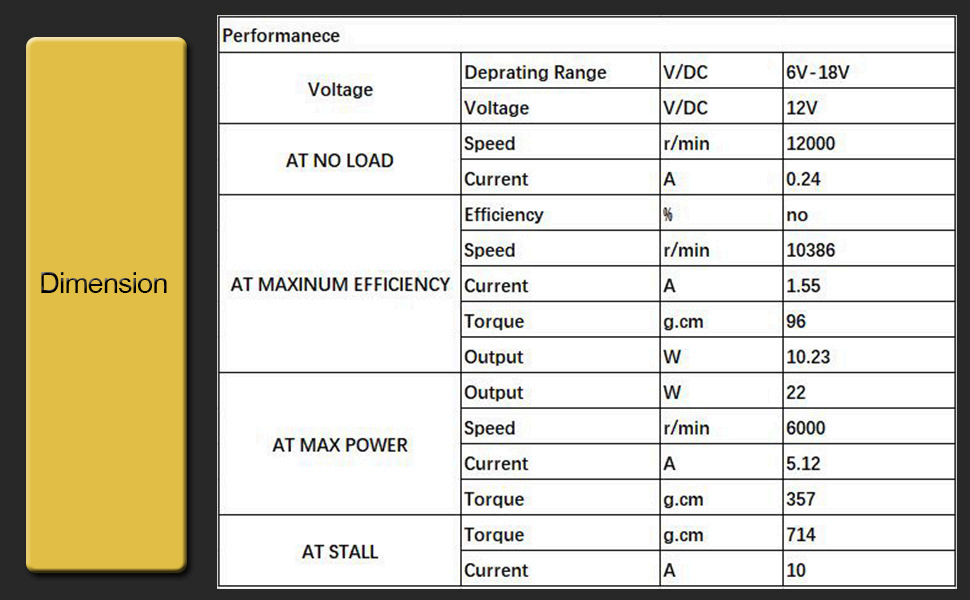
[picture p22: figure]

Also, starting today, the name of the vertical profiling float will be the Gargoyle I.

3/19

## Linear Actuator Design

Today, I gathered materials to begin the design process of the linear actuator. We found an M7 bolt with the corresponding nuts, as well as some bearings. The first task I decided on was to begin designing a gearbox.

Design by Retsetman
Instead of mounting the bolt to the motor directly, it would be superior to use a gearbox. A gearbox allows us to convert rotational speed into torque, while also allowing for flexibility with the orientation of the motor.
The gear ratio is critical to the force the linear actuator can deliver. Gear ratios dictate the amount of torque exerted in relation to the rotational speed. The leftmost number is the number of revolutions made by the driver gear, which is the gear being rotated by the motor, while the rightmost number is the number of revolutions made by the output gear. For example, a 1:2 gear ratio means the output gear rotates 2 times for every one rotation from the driver gear. This means that the speed is doubled, but the torque exerted is halved. Conversely, a 2:1 gear ratio means that the output gear rotates once for every 2 rotations from the driver gear. This means that the torque exerted is doubled, while the speed is halved.

For our application, the exerted torque (and thus force) is favored over speed. The decrease in speed alone actually benefits the float, since this allows for more precision in achieving neutral buoyancy. However, this does not mean an extremely high gear ratio should be used. As the gear ratio increases, friction will increase, straining the motor, consuming more power, and causing the movement to become inconsistent, provided it doesn’t stop entirely.
Many electric linear actuators have gear ratios ranging from 10:1 to 100:1. While the gears themselves have not been finalized, I have 3D printed gears of a 2 cm diameter with 27 teeth. Gear teeth are essential for evaluating the gear ratio of a gearbox. For example, if the driver gear has 9 teeth and the output gear has 27 teeth, the gear ratio is 3:1. I currently plan to use a 10:1 gear ratio at maximum.

Lubricant is also a notable component of linear actuators. Most linear actuators possess lubricant in both the arm and the gearbox to ensure smooth motion. Should lubrication be necessary, food-grade silicone spray/grease can be used; however, I have not yet determined whether lubrication is required at this time. This is because it is highly likely that I will be using 3D-printed gears rather than gears carved from wood or made from metal.
3/23

## Actuator Gearbox Design

In Onshape, a few designs were drafted in an attempt to experiment with the possible combinations of gears I could make. I ended up with two main designs, one with two gears and one with three gears.

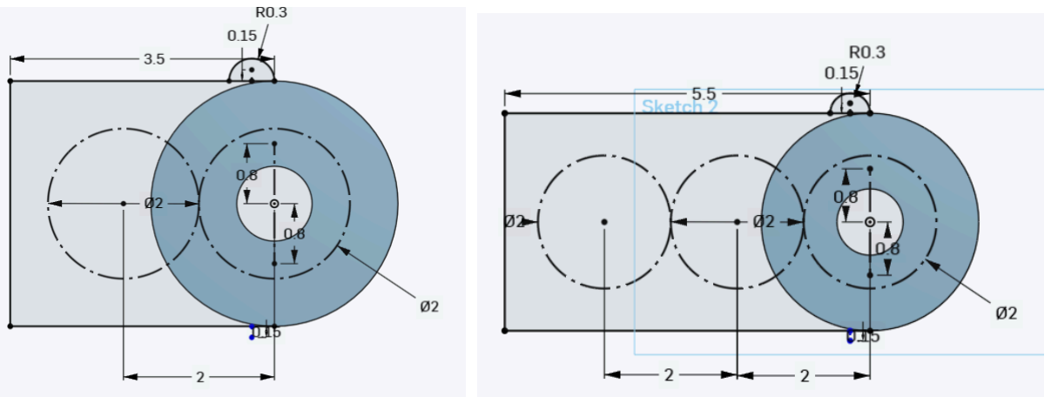
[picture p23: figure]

Each of these designs came out to be less than 10cm wide on each side. The two-gear design actually ended up being too small; the extra space was needed for the arm. The three-gear design was slightly better, although space could be optimized. The key problem with both designs was that they ended up using a good amount of space for a 1:1 gear ratio. In my research, I was able to find a website called Gear Generator 2, which helped us learn about gear ratios even further.

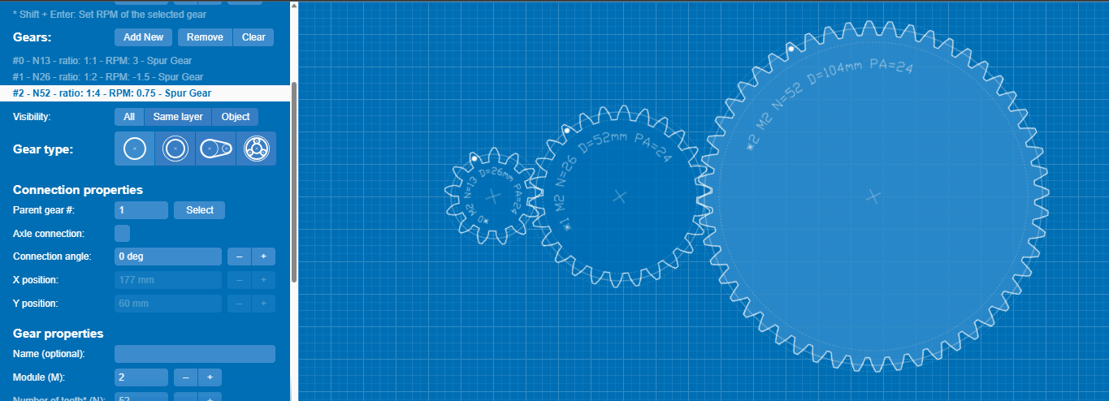
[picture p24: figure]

Using the website, I found that to even achieve a 4:1 gear ratio using regular spur gears would take far too much space. Therefore, it would be best to use compound gears. Compound gears often have smaller gears stacked on top of a bigger gear. These types of gears are commonly used in gearboxes and can provide higher torque in a smaller area. Using this knowledge, I was able to achieve a 4:1 gear ratio in less space.

With the help of a website called STLGears.com, I was able to prototype gears with a 3D printer. Through this, I was able to print out regular spur gears, but designs with overhang could not be printed correctly.

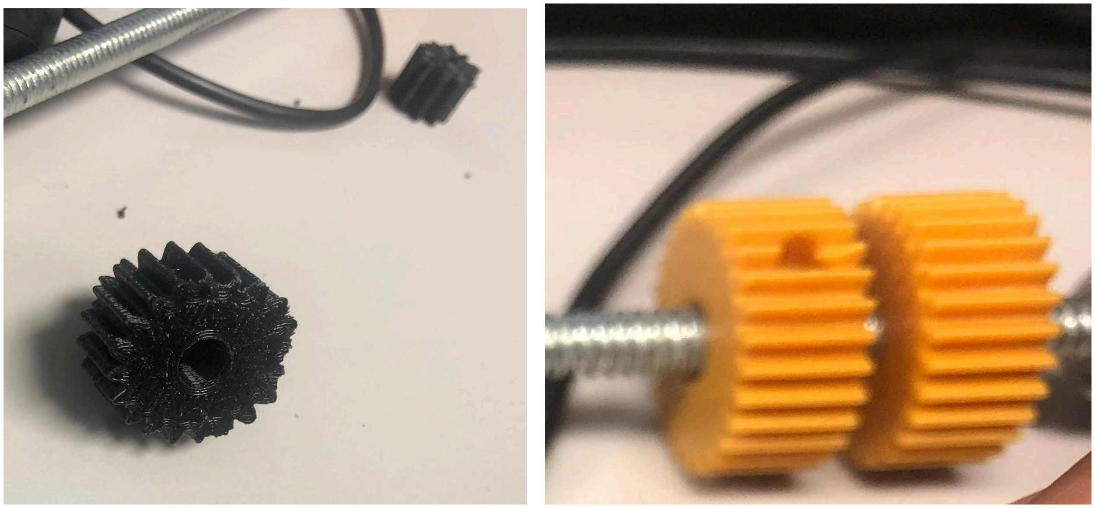
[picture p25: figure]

I was able to come up with a design for the gearbox that takes these new gears into account.

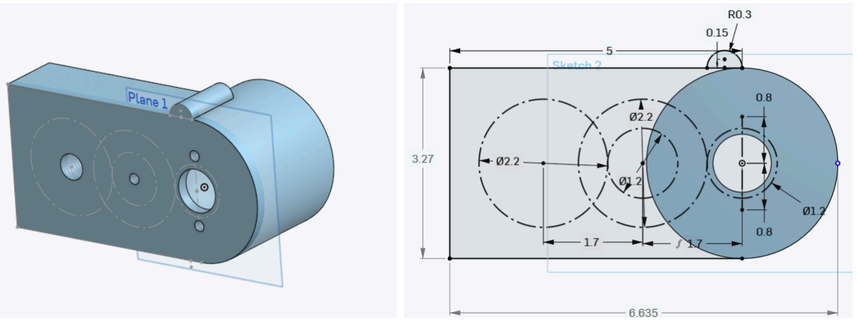
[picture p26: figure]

3/26

## Actuator Gearbox Design

Today, I was able to finalize the gears the actuator will use. The driver gear will be a 10-tooth gear with a module of 1. The module of a gear is the ratio of the gear’s pitch circle diameter, which is its diameter without the teeth in millimeters, to the number of teeth the gear has. All gears that are meshed together must have the same module. All gears will have a module of 1 to ensure precise movement and conserve space. The middle gear will be a compound gear with a 20-tooth bottom gear and a 10-tooth top gear. The top gear will be meshed with another 20-tooth gear that will be attached to the M7 bolt to be rotated. This gearbox has an 8:1 gear ratio. As of this time, the driver gear has been permanently attached to the motor.

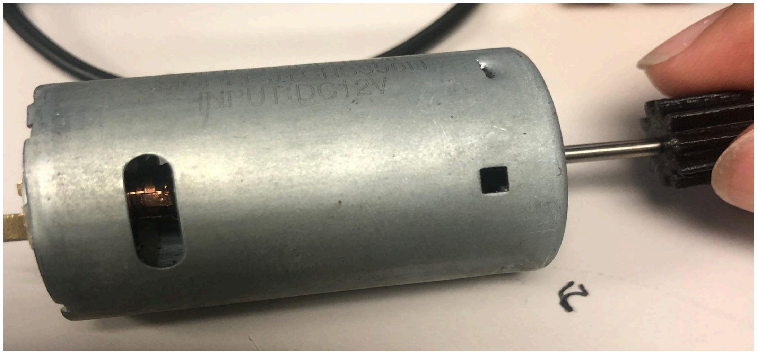
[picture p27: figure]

With the exception of the driver gear, all other gears require an axle, which is typically a rod that provides rotary motion and stability for the gears. Each axle will also require at least one, but generally two bearings, which are machine elements that hold the axle in place and reduce friction during rotation. The bearings I have on hand are plain bearings, which use sliding surfaces with lubricant to reduce friction.

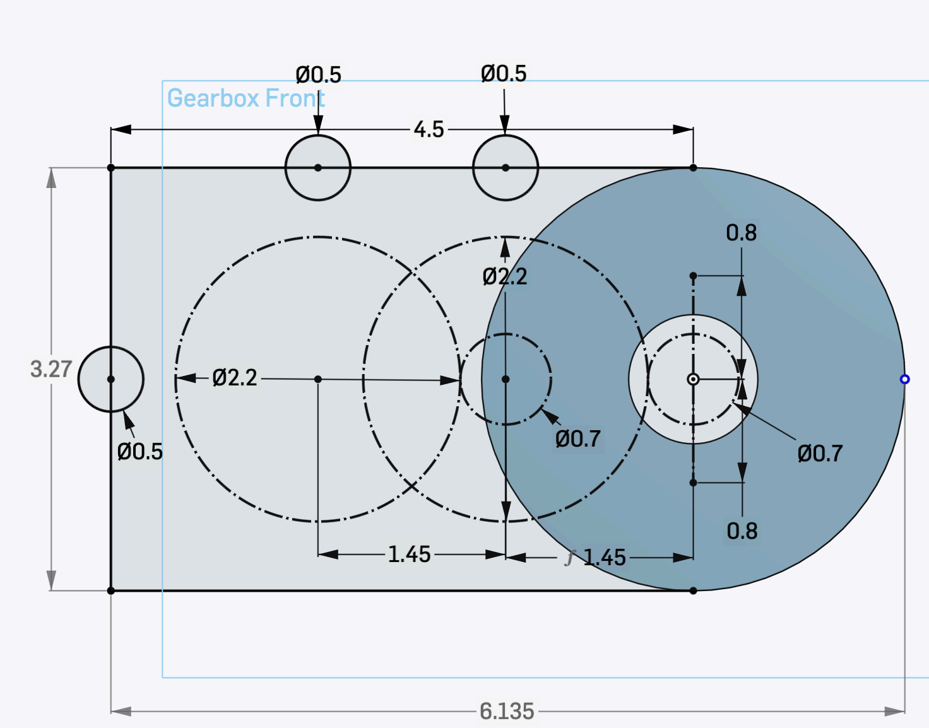
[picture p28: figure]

The gearbox has also undergone revisions to reflect these changes. In the middle, there is now space for a bearing with a 6 cm inner diameter (ID). However, this hole is not deep enough, and making it deeper would conflict with the housing of the motor. Depending on the orientation of the gears, this may not be a large issue, but it should be considered. Additionally, there are now holes surrounding the gearbox. These holes are meant for M4 nuts and bolts that will secure both parts of the gearbox.

## Initial Gear Prototyping

Unfortunately, through further prototyping, I found that the gearbox’s design would not fit our needs.

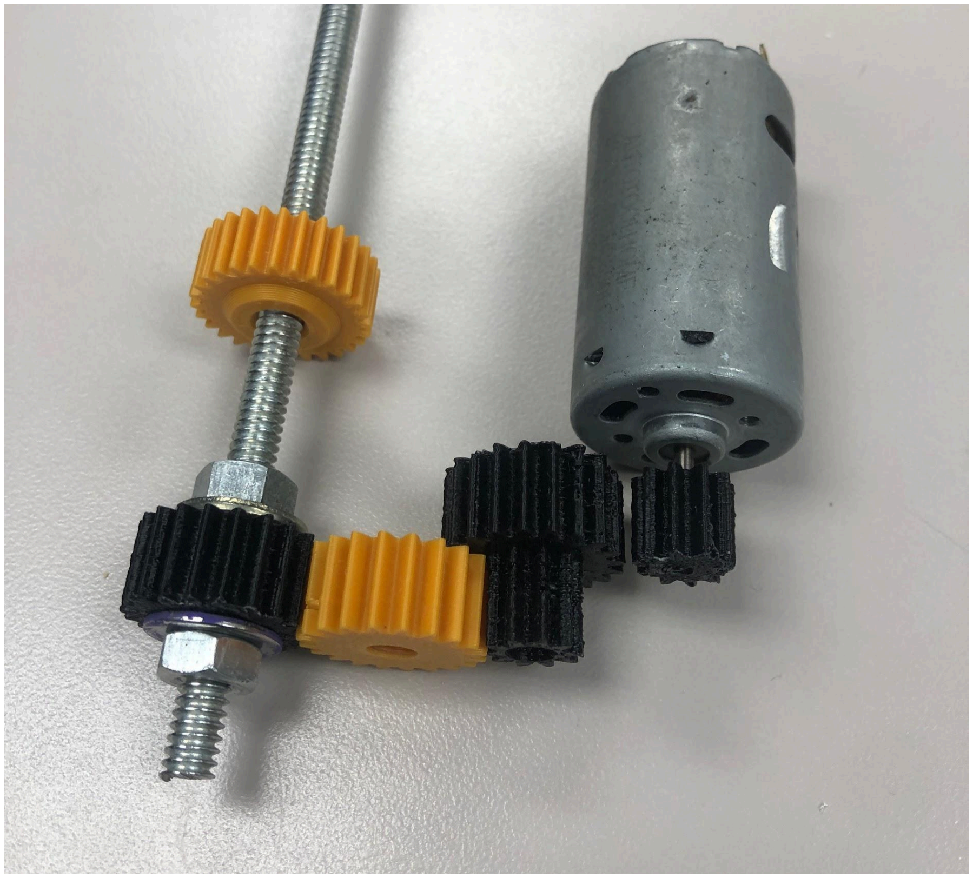
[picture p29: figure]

If the gearbox were to utilize only three gears, then there would be no space for the compound gear to mesh with the rod correctly. One solution would be to add a fourth gear that results in the same ratio. This will end up taking some space, but the main problem is that this will require another axle, which also requires another bearing. In short, this would increase the complexity of the design further than necessary. The other solution is to use a bigger gear.
Additionally, the compound gear also needs to be redesigned so that the top gear is slightly thicker than the bottom for easier meshing.

## Actuator Arm Progress

Progress has also been made on the actuator’s arm. The arm will be made of a smaller PVC pipe to save time on fabrication.

Linear actuators of this kind require a driver nut. This is the nut that will be used to hold down and displace the arm when the M7 bolt is being rotated by the motor. The idea was to use a cork with a hole to fit the nut in, then place the cork in the middle of the arm (to distribute the load). However, it is important that the hole for the nut is in the middle. Currently, I do not possess the tools to make holes with the required precision, so I will be using a 3D printed design to compensate.

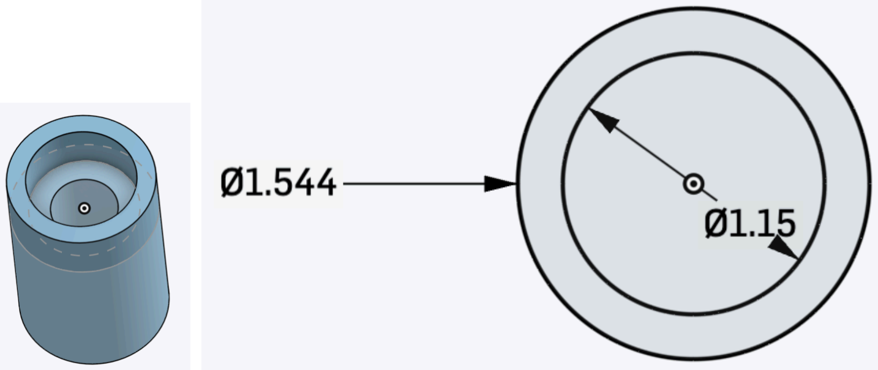
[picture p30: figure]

This design was made with the diameters of both the PVC arm and the nut in mind. This design will rely on friction to fit both the nut and the cork, then use epoxy to secure them in place.

4/2

## Name Change

As of today, the float will be named the Tiger Tower I. This was not my choice.

## Linear Actuator Revisions

### Driver Nut Holder

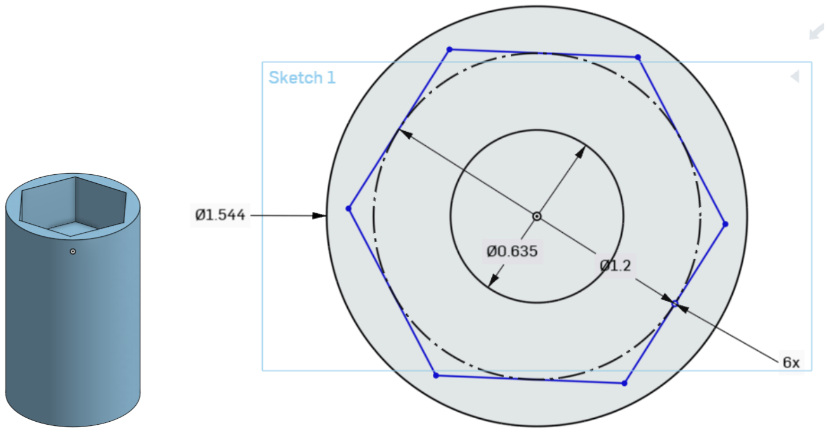
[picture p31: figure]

The holder was redesigned to have a hexagonal shape rather than a circular shape. Instead of relying on friction to fit the nut, it will instead be glued with epoxy. Additionally, the diameter of the holder was slightly increased for better friction. Currently, this is the 5th iteration of this holder, and future iterations will likely have space for nuts on both sides for better load management. Additionally, the driver nut may be placed near the gearbox instead of the middle for better space, but this may affect the way it manages load.

### Compound Gear and Bolt Gear

Both the compound gear and bolt gear have been redesigned.

As mentioned on March 26th, the compound gear had various issues that prevented it from being used in the gearbox. To alleviate this, the smaller gear was lengthened for easier meshing, and the diameter has been adjusted to fit the axle.
Additionally, the bolt gear was given an increase in diameter by giving it more teeth, allowing it to maintain its module and gear ratio while increasing the distance between the compound gear and the bolt.

### Gearbox Redesign

Each location of the hole has been readjusted to better fit the sizes of the inner diameters of each gear. The reference (construction) circles intersect each other at one or two points so that the gears will mesh correctly.

## Remaining Tasks for the Actuator

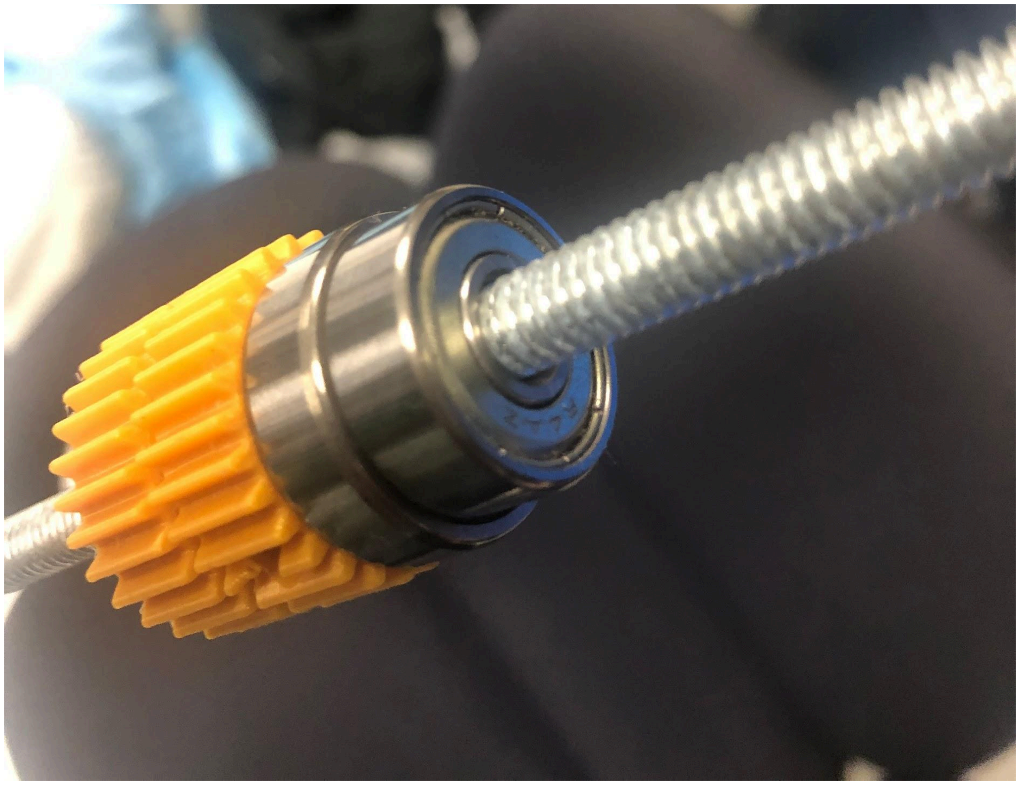
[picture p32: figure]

The bolt (which is now identified as a ¼ inch bolt) is an axle and still requires its own bearing to ensure smooth motion. However, most bearings do not accommodate bolts. Depicted in this picture is an R4AZZ bearing (https://bearingfinder.ntnamericas.com/item/deep-groove-ball-bearings/single-row-radial-ball-bearings/r4azz) placed on this bolt. It may seem like the bearing fits perfectly, but there is too much clearance (or a difference in space) for the bearing to work properly. There are two ways to get around this.
The first method is to 3D print a spacer to attach to the bolt so that it can be fit into a 608-2RS bearing. (https://bearingsdirect.com/608-2rs-sealed-ball-bearing-8x22x7-mr608-2rs/) This, however, will require a great amount of precision to fit properly. It should be noted that when using friction to fit parts into a space, the perimeter of the space should not be exactly the same as the part. For example, if there is a 6 cm diameter circular component, it will be nearly impossible to fit it into a 6 cm diameter hole. Instead, the hole should be 6.05 cm to allow for tolerance. Tolerance is a deviation from the intended dimension to account for the fact that absolute precision is not guaranteed. A small tolerance can be used for parts that can be hammered in, like the axle bearing, and a (relatively) larger tolerance can be used for parts that can be placed by hand, like the driver nut holder.

The second method is to use a ¼ in. nut and use it as a spacer for an even bigger washer. This will require slightly more space while allowing us more leniency in achieving a high level of precision.
4/10

## Linear Actuator

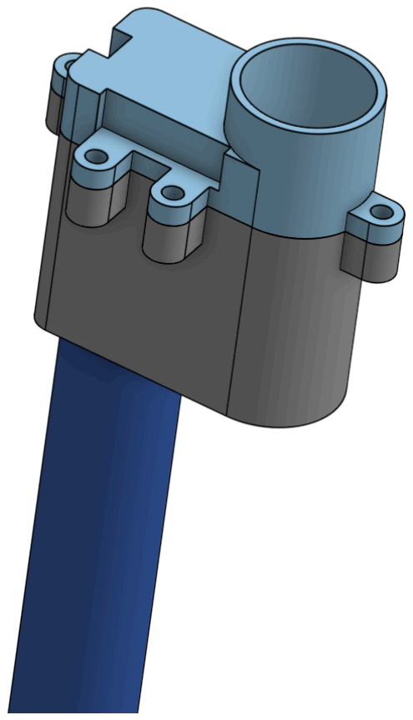
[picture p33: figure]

Now that the linear actuator is nearing completion (save for a few key issues), it is time to assemble the other components and prepare the chassis for the assembly of the vertical profiling float.

### Full Design of the Gearbox

Above is the full design of the gearbox. The motor housing remains unchanged, but the shell itself has been given a bevel on the sides to reduce material and increase strength. The orientation of the gearbox has been adjusted so that it will face down, and not up, as seen in previous designs. Finally, the gearbox will be secured with 4 M4 bolts, instead of
3. This is to evenly distribute the load.

### Final Arm Revisions

The arm has undergone minor changes since the finalization of the gearbox design.

The driver nut holder was redesigned to have a wider base below the uniform cylinder. This is to cause friction between the pipe that will contain the arm, which is necessary to ensure that the arm itself cannot rotate.

The arm will also have a 2-inch diameter piston to help better distribute the load.

### Linear Actuator Circuitry

The linear actuator will require some additional circuitry. One of the main reasons a linear actuator can fail is due to overextension. If there is no limit to how far the arm can extend or retract, the motor can fail, or the arm can be damaged. Such a scenario would be devastating to our float’s movement, so it would be best to limit how far the arm can extend.
The first idea was to use diodes to limit the current to one direction so that the arm can only be reversed once it hits a limit.

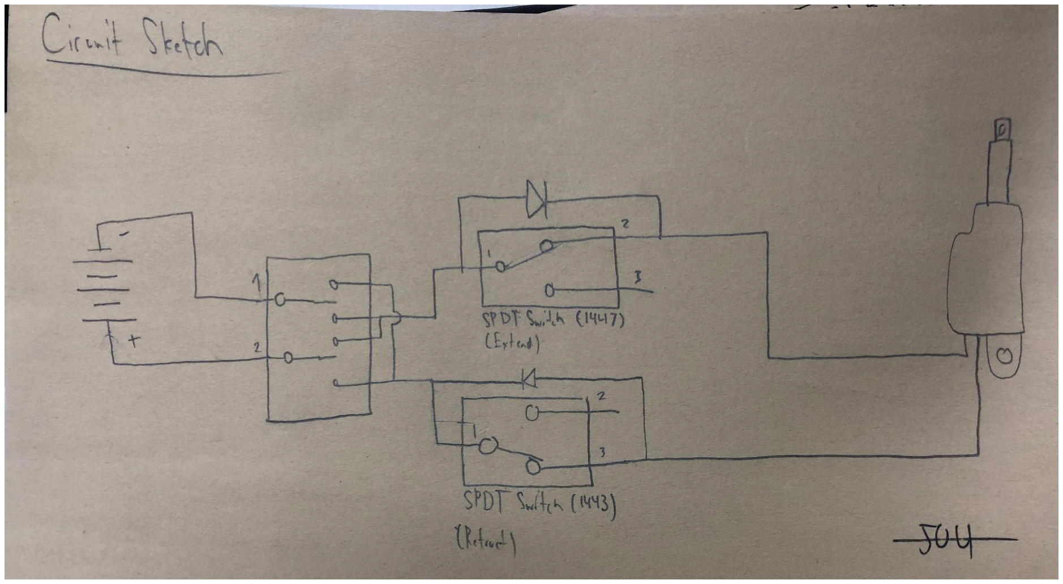
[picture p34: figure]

However, the motor will likely be drawing 5 amps of current at maximum, and there will already be a fuse to stop such a thing. What’s more dangerous is that the diodes available to us can only handle 1 amp of current, and there is no way to limit it without limiting the motor’s power. Therefore, a solution with the microcontroller will need to be developed so that a much smaller current can be used in this way. In any case, limiter switches will need to be collected, and the arm will need a way to toggle them.

4/12

## Gearbox Assembly

### Gearbox Printing

Using Onshape, I exported the STL files and printed them out. However, there were some key adjustments that made this possible. Namely, I needed to enable support on my prints. This is because both parts of the gearbox contain overhang. As the name suggests, these sections of the model hang in the air. In other words, these parts are elevated and contain no support on their own. Without some structural support below, the filament will simply fall.

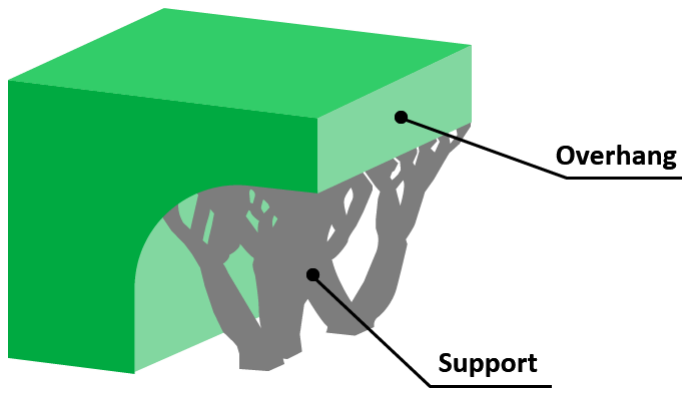
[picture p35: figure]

To alleviate this, most 3D printing studios, including Bambu Lab, allow for adding support to overhangs. I specifically used the tree support to save filament and allow for easier removal.

Additionally, I used a gyroid infill pattern instead of a rectilinear pattern. In my research, we found that using a gyroid infill pattern could provide greater strength with less material, at the expense of density.

### Spacer Solution

As mentioned before, the bolt would require a spacer to fit snugly in the R4AZZ bearing. Additionally, the holes made in the gearbox to fit the bearings were off by a small amount. In retrospect, it would have been more productive to print test holes to find the correct diameter needed. Using a digital caliper to find exact measurements was a step in the right direction, but the diameter would need to be adjusted by a small amount to provide sufficient clearance.
In the meantime, using tape proved to be a fast solution for this problem, as it fills the roles of the spacer while also being removable, if needed. This may become a permanent solution.

### Arm Assembly

Both the piston and driver nut have been printed and attached to the PVC pipe. The piston was originally intended to have a cone shape to distribute force better, but due to space constraints, we gave it a 2-inch diameter disk shape instead.

### Assembly Process

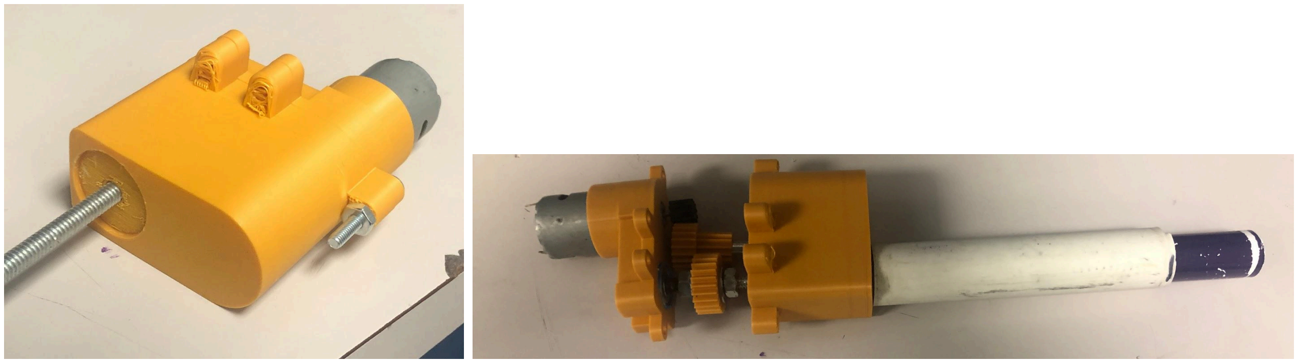
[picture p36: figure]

A small indent was made where the bolt juts out in order to fit the additional PVC pipe or the arm container. However, there were some issues with the diameters of the bearing holes, and so I would need to adjust them again. Additionally, the extrudes for the bolts don’t secure the bottom of the linear actuator; they are only able to secure the top and sides. Therefore, I need to adjust the orientation of the holes.

4/18

## Electronics Assembly

Because the linear actuator is nearing completion, I thought it would be best to prepare the electronics compartment again. Judging from what I learned 2 months ago, it was best to use a pre-existing container for the compartment.
However, most containers I found did not serve much use with my particular design. Instead, I decided to use the float as its own container while placing a silicon seal for a platform at the bottom and using the float’s o-ring cap as the top seal.

Within this compartment would be 7 components: the batteries, the fuse, the motor controller, the power switch, the pressure sensor, and the microcontroller. The platform will also contain a large hole to fit wires for the limit switches.

4/22

## Linear Actuator Platform

While the actuator is coming together, the linear actuator still needs to be affixed to the float somehow. To solve this problem, I began designing a platform that could be used to hold the linear actuator.

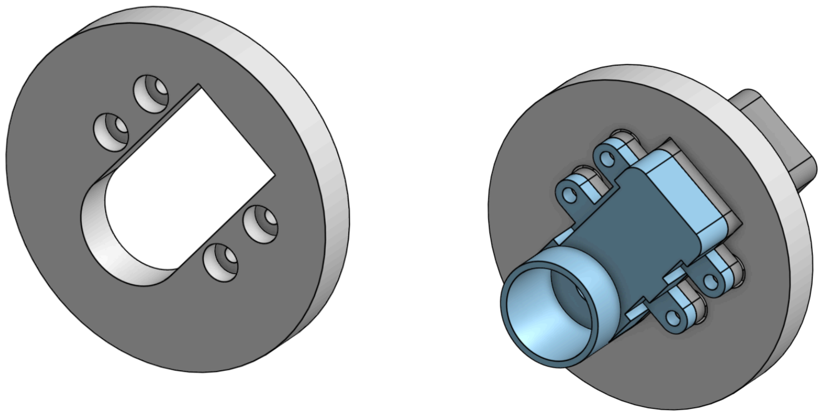
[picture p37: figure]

The idea was that I could use the cylindrical nature of the float to my advantage by creating a disk that would fit its inner diameter while adding the necessary holes to fit the actuator’s gearbox. I would then have 4 holes that the M4 bolts can be used with to secure the actuator itself. However, this disk would have to be thick to be more stable, so I made the holes counterbore holes so that I could retain the disk’s thickness while also using up less of the bolt’s length.
4/29

## Platform Redesign

Printing the platform went smoothly. I also decided to use a gyroid pattern here to increase strength, since this part is handling the linear actuator. While assembling the actuator with the platform went as expected, I found that the actuator’s arm could not be aligned at the middle of the actuator due to how the disk was designed. It is important that the arm is in the middle to distribute the load properly.
To solve this problem, I simply shifted the hole where the actuator was supposed to be to the right. However, this created a new problem: the gearbox would now escape the platform’s diameter. To alleviate this, I simply removed the section of the gearbox that was outside the diameter. This ended up being a quick solution with the added side effect of allowing the platform to be friction-fit. Originally, I had indents on the side of the platform that would allow me to increase the effective diameter of the platform with a rubber band if a friction-fit was not possible naturally. This was meant to be temporary; it was simply a way to finalize the platform’s placement before gluing it to the inner chassis.

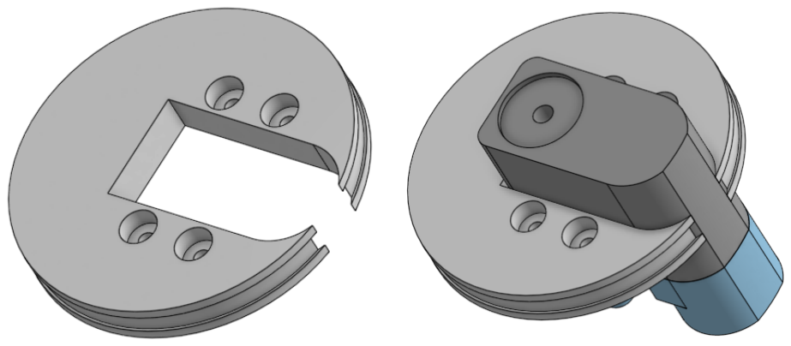
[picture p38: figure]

## Electronics + Interface Development

Today, I was able to take my Raspberry Pi Pico W home to program the interface. While I was not able to secure any alternative modules or microcontrollers, I believe that this alone will be sufficient for our operations.
A key part of my choice to use the Raspberry Pi Pico W was its innate capability to use Wi-Fi. Using this, I am able to host a server with the Pico, which allows me to send it commands through a website interface.
The Raspberry Pi Pico also possesses a way to convert the 4.8V input into a 5V input, which can be used to power the L298N motor controller I’ve been provided. It can also be used to power and support an SD card adapter. Having the data for every profile can streamline testing, but due to time constraints, it will likely have to be removed. Like most microcontrollers, the Pico also has analog pins, which will be used to read the input from the pressure sensor. These pins can go from 0V to 3.3V, and I can write code to interpret the voltage as usable data, like the current depth of the float. Two digital pins will be dedicated to the limit switches, while two more will be used to control the motors using the controller.

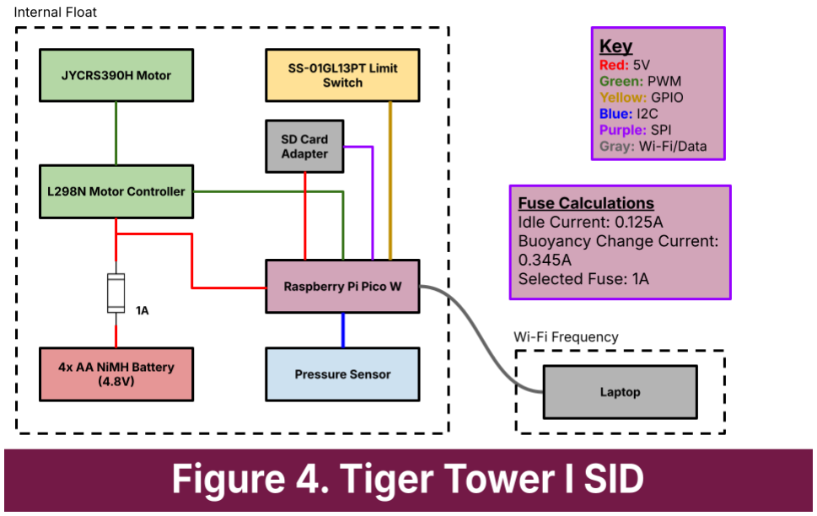
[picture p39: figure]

5/1

## Conclusion of Construction

Despite the progress made with the linear actuator and its interface, unfortunately, I will not have time to complete this float in time for the Houston MATE 2026 competition. There are problems with our ROV, Hammerhead I, that must be addressed quickly before Friday. Additionally, with AP exams rolling around in addition to being shorthanded, I will have to attempt to fix some of Hammerhead I’s problems while also practicing piloting. However, this competition is one that exemplifies iteration and posterity. Because of that, it would be best to leave the float as it is now without making any permanent changes to the chassis in the hopes that this logbook can be used to finish or adapt the project by my juniors.

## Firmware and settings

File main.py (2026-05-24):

import machine
import network
import socket
from time import sleep
from wifi_info import ssid, password, pico_ip, subnet, gateway, dns
#import sdcard
#import uos
from enum import Enum

# NOTE: Scrapping SD card idea

# Pin Configuration
"""
Pin List:
x2 Limit Switch [IN] (GPIO0, GPIO1) {NOTE: May require a low-value resistor for safe HIGH reading; make sure pins don't go above 3.3V otherwise}
L298N Motor Controller IN1, IN2 [OUT] (GPIO16, GPIO17)
Pressure Sensor Signal [IN, ADC (Analog)] (GPIO22) {NOTE: Check to make sure signal CANNOT go above 3.3V}
SD Card [SPI] (MISO: GPIO8, SCK: GPIO10, MOSI: GPIO11) (Deprecated)
"""

"""
CS = machine.Pin(9, machine.Pin.OUT) # Configure the Chip Select pin
spi = machine.SPI(1, # Initialize SPI1 with the *specified pins* and baud rate
                  baudrate=1000000,
                  polarity=0,
                  phase=0,
                  bits=8,
                  firstbit=machine.SPI.MSB,
                  sck=machine.Pin(10),
                  mosi=machine.Pin(11),
                  miso=machine.Pin(8))
"""
sensor_pin = machine.Pin(22, machine.Pin.IN) # ANALOG Value
pressure_sensor = machine.ADC(sensor_pin)
limitsw_upper = machine.Pin(0, machine.Pin.IN, machine.Pin.PULL_DOWN)
limitsw_lower = machine.Pin(1, machine.Pin.IN, machine.Pin.PULL_DOWN)
motor_in1 = machine.Pin(16, machine.Pin.OUT)
motor_in2 = machine.Pin(17, machine.Pin.OUT)

# Global Variables
class Status(Enum):
    ACTIVE = 0 # Ready for profiling. Default state.
    COMPLETED = 1 # Profiling was successful.
    ABORTED = 2 # Profiling failed.
current_state = Status.ACTIVE
depth = 0
pressure = 0
depth_list = [] # List of depths taken across 5-second intervals. Will contain 7 entries max.
pressure_list = [] # List of pressure values taken across 5-second intervals. Will contain 7 entries max.

# Constants
# TODO: Decide units
WATER_DENSITY = 0.1 # The density of the water.
MARGIN = 1 # The margin of error for the target depth.
OFFSET = 1 # The offset of the sensor from the depth of the float, recorded from the top.
DEPTH_1 = 0 # Target depth #1.
DEPTH_2 = 0 # Target depth #2.

# Connects to WLAN.
def connect():
    connection = False
        
    while connection == False:
        wlan = network.WLAN(network.STA_IF)
        wlan.active(True)
        wlan.ifconfig((pico_ip, subnet, gateway, dns))
        wlan.connect(ssid, password)
    
        for count in range(5):
            if wlan.isconnected() == True:
                connection = True
            else:
                print('Waiting for connection...', count, end='\r')
                sleep(1)

    ip = wlan.ifconfig()[0]
    print(f'Connected on {ip}')
    return ip

# Opens a socket.
def open_socket(ip):
  address = (ip, 80)
  connection = socket.socket()
  connection.bind(address)
  connection.listen(1)
  return connection

# Returns an HTML page.
def webpage(state):
  html = f"""
      <!DOCTYPE html>
      <html>
      <form action="./submerge">
      <input type="submit" value="Submerge" />
      </form>
      <p>LED is {state}</p>
      </body>
      </html>
      """
  return str(html)

# Starts a web server.
def serve(connection):
  state = 'OFF'
  while True:
    client = connection.accept()[0]
    request = client.recv(1024)
    request = str(request)
    try:
      request = request.split()[1]
    except IndexError:
      pass
    if request == '/submerge?':
      state = 'ON'
      # Begin vertical profile & sever Wi-Fi connection
      # TODO: Make buttons for 2 separate vertical profiles (1 and 2)
    html = webpage(state)
    client.send(html)
    client.close()

# Request a Wi-Fi connection.
# This function will likely need to be run twice.
# This is because once the submerge function is called, the Wi-Fi connection will be lost due to water.
# Once the float re-emerges, this function will be called again in order to transmit data.
def request_connection():
    try:
      ip = connect()
      connection = open_socket(ip)
      serve(connection)
    except KeyboardInterrupt: # Will not work remotely; flip the float's switch off and on again for a reset.
      machine.reset()
      
# Records the water pressure and current height from the pressure sensor's signal.
# This will be called every half-second to check the float's depth.
# Once the float is at a given depth, the data from this function will be recorded every 5 seconds.
def sensor_read():
    # Note: We are not using a traditional water pressure sensor, so the values may have to be played with for accuracy
    # Note: Units need to be decided (SI could be used)
    sensor_inp = pressure_sensor.read_u16() # Returns a 16-bit value. (0 - 65535)
    voltage = sensor_inp * (3.3 / 65535)
    if sensor_inp == 0: # Default values (on surface)
        depth = 0
        pressure = 0
    else: # Calculate depth and pressure.
        pass


# Pushes the piston down, expelling water and causing the float to rise.
# This will fail if the lower switch is pushed.
def piston_down():
    if limitsw_lower != 1:
        motor_in1.high()
        motor_in2.low()

# Pushes the piston up, intaking water and causing the float to sink.
# This will fail if the upper switch is pushed.
def piston_up():
    if limitsw_upper != 1:
        motor_in1.low()
        motor_in2.high()

def piston_stop():
    motor_in1.low()
    motor_in2.low()

# the hard part.
def find_neutral_buoyancy(depth : int):
    pass
    

def vertical_profile(target_depth : int):
    # Note: maybe add a fail safe? 
    # Phase 1: Descent/Ascent
    if (depth < target_depth): # If the float's current depth is below target depth...
        while depth < (target_depth - MARGIN):
            if limitsw_upper != 1:
                piston_up()
            sensor_read()
            sleep(0.2)
    elif depth > target_depth: # If the float's current depth is above target depth...
        while depth > (target_depth + MARGIN):
            if limitsw_lower != 1:
                piston_down()
            sensor_read()
            sleep(0.2)
    # Phase 2: Adjustment for neutral buoyancy
    piston_stop()
    # TBD
    # Phase 3: Recording
    for i in range(6):
        depth_list.append(depth)
        pressure_list.append(pressure)
        sleep(5)
    depth_list.append(depth) # 7th entry
    pressure_list.append(pressure)
    # Phase 4: Surfacing

def task_4(depth1 : int, depth2 : int):
    depth = 0
    pressure = 0
    vertical_profile(depth1)
    pass

# Main Function

"""
# Initialize the SD card object
try:
    sd = sdcard.SDCard(spi, CS)
    # Mount the FAT filesystem
    vfs = uos.VfsFat(sd)
    uos.mount(vfs, "/sd")
    print("SD card mounted successfully!")
except:
    print("SD card missing.")
"""
request_connection()

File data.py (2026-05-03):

# Source: https://microcontrollerslab.com/micro-sd-card-module-raspberry-pi-pico/
import machine
import sdcard
import uos

# Configure the Chip Select pin
CS = machine.Pin(9, machine.Pin.OUT)

# Initialize SPI1 with the *specified pins* and baud rate
spi = machine.SPI(1,
                  baudrate=1000000,
                  polarity=0,
                  phase=0,
                  bits=8,
                  firstbit=machine.SPI.MSB,
                  sck=machine.Pin(10),
                  mosi=machine.Pin(11),
                  miso=machine.Pin(8))

# Initialize the SD card object
sd = sdcard.SDCard(spi, CS)

# Mount the FAT filesystem
vfs = uos.VfsFat(sd)
uos.mount(vfs, "/sd")

print("SD card mounted successfully!")
print("Files on SD card:", uos.listdir("/sd"))

# Create a file and write data to it
with open("/sd/data.txt", "w") as file:
    print("Writing to data.txt...")
    file.write("Welcome to microcontrollerslab!\r\n")
    file.write("This is a test\r\n")

print("Write complete.")

# Open the file and read the data back
with open("/sd/data.txt", "r") as file:
    print("Reading data.txt...")
    data = file.read()
    print(data)
